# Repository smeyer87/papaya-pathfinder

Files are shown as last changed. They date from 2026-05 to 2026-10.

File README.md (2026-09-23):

# Papaya Pathfinder — Personal Build

<div style="text-align: center;">
  Papaya Pathfinder patch
</div>

This is a personal fork of the open-source [Papaya Pathfinder](https://github.com/tronxi/papaya-pathfinder)
rover project, building the **full-size Pathfinder** with custom electronics
and a from-scratch PCB design. It is not a general-purpose reference for the
upstream project — for that (both rover variants, the Android/desktop
controllers, full parts lists, licensing), see the archived
[upstream README](docs/UPSTREAM_README.md).

This fork intentionally does **not** use `pathfinder-mini`,
`android-controller`, or `desktop-controller` — control is via a standard
R/C transmitter/receiver instead.

## Hardware

- **Controller:** ESP32-S3
- **Radio:** RadioMaster ELRS-RP3-V2 receiver + BETAFPV LiteRadio 2 SE
  transmitter (ELRS V3, 2.4 GHz) — not covered by the upstream project;
  see [`docs/elrs-wiring.md`](docs/elrs-wiring.md)
- **Motor Drivers:** 2× BTS7960/IBT_2
- **Motors:** 6× GA25 DC gear motors (3 per side, ganged — one PWM signal
  per side drives all 3 motors on that side simultaneously)
- **Steering:** 4× Miuzei DS3218 servos (front and rear axles only)
- **Power:** LiPo 3S
- **Voltage Regulation:** UBEC 5V/3A (logic) + UBEC 6V/8A (servos)

Full mechanical parts list and 3D-printable files are unchanged from
upstream — see the [3D-Printed Parts table](docs/UPSTREAM_README.md#3d-printed-parts)
and [`pathfinder/3d-models/`](pathfinder/3d-models/).

## Electronics & PCB design (this fork's main addition)

The stock electronics were originally point-to-point soldered onto a
pre-drilled prototyping board. That's being replaced with a custom PCB,
designed via a YAML-first workflow rather than starting cold in KiCad:

- **[`papaya-wiring-layout.yaml`](papaya-wiring-layout.yaml)** — the single
  source of truth for the *entire* electrical system (battery, fuse,
  switch, terminal blocks, motor drivers, UBECs, ESP32, ELRS receiver,
  motors, servos, and the board's own connectors), not just the board.
  Real wire gauges, real terminal numbering, ground loop verified closed.
- **[`pathfinder/kicad/papaya-pcb/`](pathfinder/kicad/papaya-pcb/)** — the
  KiCad 10 project. The schematic is generated (see below), not hand-drawn;
  the layout, copper pours, routing, and 4 corner mounting holes were then
  done by hand and verified with `kicad-cli` DRC (0 violations) and a full
  net-by-net comparison against the YAML.
- **[`pathfinder/kicad/scripts/generate_schematic.py`](pathfinder/kicad/scripts/generate_schematic.py)** —
  reads the wiring YAML and writes a fully-wired starter schematic (every
  component placed, every net labeled), validated against real KiCad 10 with
  zero ERC errors. Re-run it any time the YAML changes:
  ```
  pip install -r pathfinder/kicad/scripts/requirements.txt
  python pathfinder/kicad/scripts/generate_schematic.py
  ```
- **[`pathfinder/kicad/papaya-pcb/gerbers/`](pathfinder/kicad/papaya-pcb/gerbers/)** —
  fabrication output (Gerbers, Excellon drill file, drill map, job file, and
  a zip of the set) for the board revision ordered from OSH Park.

See **[`docs/development-log.md`](docs/development-log.md)** for the full
write-up of how the wiring model, schematic generator, and PCB layout were
built, and the Phase 1 bring-up narrative (including two real hardware
defects found and fixed — see the ADRs below).

**Status: Phase 1 complete** (2026-09-19) — the rover drives under full
ELRS control. See
[`docs/superpowers/specs/2026-08-16-phase1-current-state.md`](docs/superpowers/specs/2026-08-16-phase1-current-state.md)
for the exit-criteria checklist.

## Documentation

- **[`docs/build-guide.md`](docs/build-guide.md) — start here if you're
  building one of these from scratch**: full parts list through
  fabrication, assembly, firmware flashing, and bring-up testing, written
  to route around every mistake made during this build.
- [`docs/build-notes.md`](docs/build-notes.md) — build journal, gap
  analysis vs. the upstream docs, project goals for this fork
- [`docs/elrs-wiring.md`](docs/elrs-wiring.md) — ELRS receiver wiring,
  binding, and RC channel mapping
- [`docs/servo-zeroing.md`](docs/servo-zeroing.md) — flashing firmware and
  validating steering servo centering
- [`docs/development-log.md`](docs/development-log.md) — wiring model,
  KiCad generator, PCB layout, and Phase 1 bring-up narrative
- [`docs/adr/`](docs/adr/) — architecture decision records for two hardware
  defects found post-fabrication (ESP32 header pin trimming; servo header
  ground isolation) and how they were resolved
- [`docs/phase2/inputs/`](docs/phase2/inputs/) — Phase 2 planning input
  templates (missions, capabilities, sensors/compute, platform,
  assumptions/decisions) feeding the Phase 2 design session
- [`docs/UPSTREAM_README.md`](docs/UPSTREAM_README.md) — archived original
  project README (both rover variants, full parts tables, controllers)

## License

This project is licensed under the **Apache License 2.0** — see
[LICENSE](LICENSE). This fork is derived from
[tronxi/papaya-pathfinder](https://github.com/tronxi/papaya-pathfinder);
see [`docs/UPSTREAM_README.md`](docs/UPSTREAM_README.md) for original
project attribution.

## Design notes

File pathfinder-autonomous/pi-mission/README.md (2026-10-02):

# Papaya Pathfinder — Pi Mission

The MP-1 ("Map/Detect/Explore") mission software: GPS+IMU dead-reckoning
position fusion with a growing error-circle, boustrophedon
coverage-pattern generation, exclusion-zone intrusion checks, obstacle
detection/classification and resume-after-restart reconciliation, and
`MissionRuntime` — the orchestrator that ties all of it into one running
process (startup/resume, the tick loop, command handling, telemetry
cadence, Home-return sync). See
`../../docs/superpowers/specs/2026-09-24-mp1-map-detect-explore-design.md`
for the design this implements, and the "Mission Runtime" section below
for how it actually runs.

`GpsFix`/`ImuReading` are plain data; a sensor-driver layer underneath
`MissionRuntime` produces them from either real or simulated hardware
(see "Sensing backends" below) — this package's own math modules
(`position_fusion.py`, `coverage_pattern.py`, etc.) never touch hardware
directly. Persistence is local-first: `local_store.py`'s SQLite store
holds obstacles/sweep-sessions/telemetry, synced to the backend at a
Home-return checkpoint by `sync_client.py`.

**Time handling:** `position_fusion.py`'s `timestamp` fields are
monotonic seconds (e.g. `time.monotonic()`), used only for computing
elapsed-time deltas -- never wall-clock time. Everything else
(`Obstacle.first_detected_at`, `detected_at`, `now`) is a real UTC
`datetime`.

**Bearing convention:** ultrasonic/camera detections report a bearing
relative to the rover's own heading (0 = straight ahead), not an
absolute compass bearing -- the mast rotates independently of the
chassis. `obstacle_detection.py` combines it with the rover's current
heading before placing the obstacle.

## Run the tests

    python3 -m venv .venv
    source .venv/bin/activate   # Windows: .venv\Scripts\activate
    pip install -r requirements.txt
    pytest -v

## Modules

- `position_fusion.py` — `PositionFusion`: seed with a `GpsFix`, feed
  `ImuReading`s between fixes, read `.current_estimate` for the fused
  position + heading + error-circle radius.
- `coverage_pattern.py` — `generate_coverage_pattern(inclusive, exclusions,
  row_spacing_m)`: ordered lawnmower *legs* — a list of contiguous
  `(lon, lat)` polylines. Each leg is independently drivable; routing
  between legs is the caller's job (an exclusion zone may sit in the gap).
- `exclusion_check.py` — `find_intruded_exclusion(position, exclusions)`:
  which exclusion zone (if any) a position is inside, and how deep.
- `geo_utils.py` — shared degrees/meters helpers (`project_position`,
  `flat_earth_distance_m`) used by every other module.
- `obstacle.py` — `Obstacle`: the detection domain object.
- `classification.py` — `classify_permanence(type, confidence)`: the
  permanent/temporary heuristic, with a low-confidence safety override.
- `obstacle_detection.py` — turns a sensor detection (ultrasonic+camera
  relative-bearing/range, or a bump contact) into an `Obstacle` at an
  absolute position.
- `resume_validation.py` — `reconcile_obstacles(known, fresh, now)`:
  confirms, clears, or flags-as-discrepancy previously known obstacles
  during a resume pass.
- `row_spacing.py` — derives coverage row spacing from sensor detection
  width; validates it against the rover's chosen turn style
  (spin-in-place vs. graceful) and turn diameter.
- `sweep_session.py` — the sweep-session state machine (start/
  interrupt/resume/complete). Build one from a coverage pattern with
  `SweepSession.from_legs(legs, ...)`, which tags each waypoint with its
  `leg_index` so leg boundaries survive; never flatten the legs yourself.
- `exclusion_decision.py` — auto-reverse vs. wait-for-help.
- `gps_loss_decision.py` — continue-on-dead-reckoning vs. stop-and-alert.
- `local_store.py` — SQLite local store for obstacles/sweep-sessions/
  telemetry. Obstacle/session saves commit immediately; telemetry saves
  defer commit to the caller (`commit()`), batched per
  `DEFAULT_TELEMETRY_COMMIT_INTERVAL_S` (currently 60s — change this one
  constant, or pass a different `interval_s` to `should_commit_telemetry`,
  if the SD-card-wear tradeoff ever needs revisiting; see the design
  spec's resolved open items).
- `telemetry_record.py` — `build_telemetry_record()`: the two-tier
  telemetry record's missing-value tagging (present / `"missing"` /
  omitted).
- `sync_client.py` — pushes unsynced local-store records to the
  backend's `/sync/*` endpoints at a Home-return checkpoint. Tests run
  against `httpx.MockTransport`, not a live server -- no MongoDB or
  running backend needed to build or test this module.
- `runtime.py` — `MissionRuntime`: the orchestrator. Owns no business
  logic of its own; ties position fusion, obstacle detection, the
  mission-flow decision modules, telemetry, and sync into one running
  process. Takes a `SensorHub` and an `Esp32Link` as constructor
  arguments (see "Sensing backends" below).
- `runtime_config.py` — named constants and `.env`-loaded settings
  (`TICK_HZ`, poll/sample intervals, GPS-loss thresholds, etc.).
- `esp32_link.py` / `sensor_hub.py` — the `Esp32Link`/`SensorHub`
  Protocols `MissionRuntime` depends on, plus `FakeEsp32Link`/
  `SimulatedSensorHub`, the scripted-per-field test doubles used by most
  of this package's own tests.
- `backend_client.py` — read/poll half of talking to the Backend Core
  API (rover/geofence fetch, command polling); `sync_client.py` is the
  push half.

### Sensing backends

Three things can sit behind the `SensorHub`/`Esp32Link` Protocols,
swapped in via `MissionRuntime`'s constructor without touching
orchestration logic:

- **`sensor_hub.py`'s `SimulatedSensorHub` / `esp32_link.py`'s
  `FakeEsp32Link`** — scripted per-field test doubles. Each test sets
  exactly the value it needs; fields have no relationship to each other.
- **`digital_twin.py`** — one coherent simulated rover world (position,
  heading, speed, a bounded mast sweep, bounded GPS jitter, bump/halt
  detection) that *derives* every sensor reading from shared state, so a
  scenario test can rely on them agreeing with each other the way real
  sensors would.
- **`hardware_esp32_link.py` / `hardware_sensor_hub.py`** — real
  implementations for the breadboard bench rig: NMEA GPS parsing, a
  BNO055-shaped IMU, HC-SR04-style ultrasonic ranging, a thin camera
  pass-through, and the real newline-delimited-JSON Pi↔ESP32 UART
  protocol. Every hardware dependency (a serial-like transport, an I2C
  device, a GPIO pulse timer) is injected via the constructor against a
  `Protocol` defined in the same file, so none of this needs real
  hardware or hardware-specific libraries (`pyserial`, `pigpio`, etc.)
  to unit-test — only to actually run against physical hardware, which
  is bench-time work (constructing the real `serial.Serial`/`pigpio.pi()`
  objects) not yet wired into `__main__.py`.
- **`status_display.py`** — an LCD status display (screen cycling, 2
  soft-key function buttons) reading `MissionRuntime.last_telemetry_
  readings`, the same hardware-driver pattern: logic is fully testable,
  the real PCF8574/1602A write backend is bench-time work.

## Mission Runtime

`python -m papaya_mission` runs the mission loop. Requires `.env` with
`ROVER_ID`, `BACKEND_BASE_URL` (the running Backend Core service), and
`LOCAL_DB_PATH` (SQLite file path — created if absent).

The CLI entrypoint (`__main__.py`) currently wires `SimulatedSensorHub`
and `FakeEsp32Link` — real hardware drivers exist (`hardware_sensor_hub.py`,
`hardware_esp32_link.py`, see "Sensing backends" above) but constructing
the actual hardware objects they're injected with (a real serial port, a
real `pigpio` connection) is bench-time work not yet done, so the CLI
entrypoint hasn't been switched over.

**Note — the swap-in story holds for sensing, not yet for motion.** The
`Esp32Link` contract currently covers bump-safety reporting and
drive-status telemetry only; it has no drive/steering-commanding method
yet, and `MissionRuntime` never issues a movement command anywhere in
`tick()`. Actual navigation (driving toward the next waypoint) is not
yet implemented: this runtime can *detect* waypoint arrival and make
mission-level decisions off it, but it has no way to *cause* that
arrival. The ESP32 firmware plan needs to add both a movement-commanding
method to `Esp32Link` and a navigation step to `tick()` before the rover
can physically move itself.

Per-tick duration is logged; a warning means a tick exceeded its
`TICK_HZ` budget — see the MP-1 Mission Runtime design notes' "Scaling
note" for what that means and what to do about it.

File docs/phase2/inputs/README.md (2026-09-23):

# Phase 2 Planning Inputs

Raw-but-organized planning notes that feed the Phase 2 design session.
These are **inputs**, not a design — nothing here is final until it lands
in a spec under `docs/superpowers/specs/` or an ADR under `docs/adr/`.

Baseline for everything here is the Phase 1 build as documented in
[`../../superpowers/specs/2026-08-16-phase1-current-state.md`](../../superpowers/specs/2026-08-16-phase1-current-state.md)
— don't re-describe Phase 1 hardware in these files, just reference it.

## Files

| # | File | Answers | ID prefix |
|---|---|---|---|
| 0 | [`00-inbox.md`](00-inbox.md) | "I don't know where this goes yet" | — |
| 1 | [`01-missions.md`](01-missions.md) | What should the rover *do*, where, and what's out of scope? | `MP-` |
| 2 | [`02-capabilities.md`](02-capabilities.md) | What logical abilities do those missions require? | `CAP-` |
| 3 | [`03-sensors-compute-electronics.md`](03-sensors-compute-electronics.md) | What sensors, compute, power, and comms hardware supports them? | `SEN-` / `CMP-` / `PWR-` / `COM-` |
| 4 | [`04-physical-platform.md`](04-physical-platform.md) | What mechanical/chassis changes does all of the above need? | `PLT-` |
| 5 | [`05-assumptions-decisions.md`](05-assumptions-decisions.md) | Constraints, assumptions, decisions made, open questions | `CON-` / `A-` / `D-` / `Q-` |

## How to fill these in

- **Don't over-sort.** If a note doesn't obviously belong somewhere, drop
  it in `00-inbox.md`. Each file also has a `Raw notes` section at the
  bottom for anything half-formed.
- **Give items IDs** (`MP-1`, `CAP-4`, …) and reference upstream IDs in a
  `Supports:` line. This is how we keep the files linked without merging
  them. IDs are permanent — if you drop an item, mark it `~~struck~~`
  rather than renumbering.
- **Top-down is ideal, bottom-up is fine.** If a note starts from a
  technology ("I want to try LIDAR"), write it where it belongs and set
  `Supports:` to the mission it enables — or to a learning goal
  (`MP-L1`, etc.) if the real reason is "I want to learn this."
- **Priority** on every mission and capability: `Must` / `Should` /
  `Could`. This is what lets an ambitious list get phased.
- **Uncertainty is valuable.** "Not sure if X or Y" goes straight into
  `05` as an open question (`Q-`) — those become the design session agenda.

## Flow

```
01 Missions ──► 02 Capabilities ──► 03 Sensors/Compute ──► 04 Platform
      │                │                     │                  │
      └────────────────┴──────────┬──────────┴──────────────────┘
                                  ▼
                   05 Constraints / Assumptions /
                      Decisions / Open Questions
```

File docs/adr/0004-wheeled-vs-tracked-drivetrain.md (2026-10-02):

# ADR 0004: Keep wheeled rocker-bogie drivetrain; reject tracked and other alternative architectures

## Status

Accepted — 2026-10-02

## Context

Phase 2 sensor/compute additions are forcing a substantial payload-bay
redesign (`docs/phase2/inputs/04-physical-platform.md` PLT-5), and a
wheel/axle redesign is already underway for two independent reasons: a
recurring printed steering-pivot-pin failure (PLT-7) and a longer
wheelbase needed to match the larger bay (Q-9, 6-vs-8-wheel). With this
much of the drivetrain already open for rework, it's a natural point to
ask whether the overall drivetrain *architecture* — not just the wheel
suspension — is still the right choice, rather than patching the current
approach without reconsidering it.

Four architectures were weighed:

1. **Tracked / caterpillar drivetrain.** Pros: better flotation/traction
   on soft or very uneven ground; steering is typically skid-steer only,
   no steering-knuckle complexity at all. Cons: track tensioners, drive
   sprockets, and track wear/replacement add significant mechanical
   complexity, weight, and cost versus wheels; track maintenance is a
   real recurring burden, not a one-time cost.
2. **Mecanum / omni wheels.** Pros: lateral/strafing movement, tight
   maneuvering in confined spaces. Cons: the small rollers that give
   omni wheels their lateral capability are known to perform poorly
   outdoors on anything but smooth, hard, flat surfaces — grass, dirt,
   and mild unevenness tend to defeat them. Wrong tool for this terrain.
3. **Fully independent coil-over suspension per wheel** (abandon the
   rocker-bogie's passive, geometry-based articulation entirely). Pros:
   simpler single-wheel kinematics; removes the transverse-differential/
   chassis-torsion coupling question entirely (see Q-11 — there'd be
   nothing to couple). Cons: loses the rocker-bogie's ability to span
   step-like obstacles via arm leverage rather than relying purely on
   spring compression; would require re-engineering every wheel mount,
   not just the one joint that's actually failing — discarding the
   "pivot"/"bogey" structural mounts that have never been a problem.
4. **Legged/walking locomotion** (e.g. a Theo Jansen-style linkage).
   Rejected quickly: a large jump in mechanical and control complexity
   with no capability benefit for a mostly-flat terrain profile.

## Decision

**Keep the existing wheeled rocker-bogie drivetrain** (6-wheel today,
likely 8-wheel per Q-9), and retrofit a knuckle-and-shock suspension at
the specific joint that's actually failing (PLT-7) rather than replacing
the drivetrain architecture.

## Rationale

- `A-2` (mild, mostly-flat farm terrain; major hazards geofenced out;
  human-walking-pace operation) doesn't demand tracked-vehicle-grade
  traction or flotation — that capability would solve a problem this
  rover doesn't have.
- The rocker-bogie's structural mounts (the "pivot"/"bogey" parts) have
  never been among the observed failure modes — reusing them, rather
  than replacing the whole architecture, avoids re-solving an
  already-solved problem.
- Tracks, mecanum, and legged locomotion all add substantial cost,
  weight, and complexity with no capability gain for this specific
  mission profile.
- None of the alternatives fix the actual observed failure anyway: the
  printed steering-pivot-pin problem (PLT-7) is a strut/joint design
  issue, not a drivetrain-architecture issue — a tracked vehicle still
  needs a mechanism translating motor rotation into motion and still
  needs shock absorption for ride quality over washboard; changing
  architecture wouldn't make the print-strength problem disappear.

## Consequences

- Keeps the existing motor/servo/driver investment valid and reusable
  (6× GA25 motors, 4× DS3218 servos, 2× BTS7960 drivers) rather than
  stranding it on an architecture change.
- Revisit if `A-2`'s terrain assumption changes — e.g. a future mission
  requires crossing genuinely soft or rough terrain wheels can't handle.
  Considered unlikely given the stated farm-terrain mission profile, but
  not foreclosed.

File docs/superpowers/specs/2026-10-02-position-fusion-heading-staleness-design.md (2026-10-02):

# PositionFusion Heading-Staleness Bug — Design

**Status:** Approved, pending plan
**Related:** `pathfinder-autonomous/pi-mission/papaya_mission/position_fusion.py`, `papaya_mission/runtime.py`

## Problem

`PositionFusion._heading_deg` only updates inside `on_imu_reading()`, which is the method that also does full dead-reckoning (position/velocity/error-radius). `MissionRuntime._read_position` (`runtime.py:315-361`) calls `on_imu_reading` **only** in the `else` branch — when no GPS fix arrived that tick:

```python
if gps_fix is not None:
    self.position_fusion.on_gps_fix(gps_fix)
    self._last_gps_fix_monotonic = now_monotonic
else:
    self.position_fusion.on_imu_reading(imu_reading)
```

On a GPS-healthy rover (the common case — a fix arrives almost every tick), `on_imu_reading` essentially never runs, so `_heading_deg` never advances past whatever it was seeded at. `obstacle_from_ultrasonic_camera_detection` (`obstacle_detection.py`) projects every detection's absolute bearing using `rover_position.heading_deg` — so every logged obstacle gets placed using a stale/zero heading, silently misplacing it, whenever GPS is working normally (i.e. almost always).

A second, related bug compounds this: the very first `PositionFusion` ever constructed, at seed time (`runtime.py:343-345`), also doesn't get a real heading —

```python
self.position_fusion = PositionFusion(seed_fix)
```

— defaults `initial_heading_deg` to `0.0`, even though a real `imu_reading` was already successfully read that same tick (the method returns early with an IMU read failure before reaching this line, so `imu_reading` is guaranteed valid here).

This bug was found during the digital-twin simulator's final review (2026-09-26), logged to memory, explicitly scoped out of that plan as pre-existing and unrelated — never fixed until now.

## `PositionFusion` itself is correct and already tested — the bug is entirely in the caller

`position_fusion.py`'s `on_gps_fix` deliberately never touches heading (position/velocity/error-radius only) — there's an existing, passing test for exactly this: `test_gps_fix_does_not_change_heading` asserts `corrected.heading_deg == 90.0  # unchanged by the GPS fix`. This is correct design: a GPS fix carries no heading information of its own, so `on_gps_fix` has nothing to update heading with. The bug is that nothing else steps in to update heading on a tick where `on_gps_fix` runs instead of `on_imu_reading`.

## Fix

Add a narrow, dedicated method to `PositionFusion` that updates **only** heading — no dt guard, no dead-reckoning math, so it can never be silently skipped the way `on_imu_reading`'s `if dt <= 0: return` guard could skip it:

```python
def on_imu_heading(self, heading_deg: float) -> None:
    self._heading_deg = heading_deg
```

Call it unconditionally, every tick, in `_read_position` — before the `gps_fix is not None` branch, so it runs regardless of which branch follows:

```python
self.position_fusion.on_imu_heading(imu_reading.heading_deg)
if gps_fix is not None:
    self.position_fusion.on_gps_fix(gps_fix)
    self._last_gps_fix_monotonic = now_monotonic
else:
    self.position_fusion.on_imu_reading(imu_reading)
```

In the no-fix branch, `on_imu_reading` will set the same heading value again — harmless redundancy, not worth adding a conditional to avoid, since correctness (heading always reflects the latest real reading) matters more than skipping one redundant assignment.

Also fix the seed-time gap: pass the real heading when constructing the first `PositionFusion`:

```python
self.position_fusion = PositionFusion(seed_fix, initial_heading_deg=imu_reading.heading_deg)
```

## Why not fold heading into `on_gps_fix` instead

Considered and rejected: calling `on_imu_reading` unconditionally every tick (even when a GPS fix also arrives) instead of adding a new method. Rejected because `on_imu_reading`'s `dt <= 0` guard (comparing `ImuReading.timestamp` against `_last_timestamp`) could still silently skip the heading update under certain tick-timing edge cases — real hardware's IMU and GPS readings may come from clocks that aren't perfectly synchronized, so this doesn't fully close the bug, just narrows it. A dedicated, guard-free method closes it completely and leaves the already-tested `on_gps_fix`/`on_imu_reading` dead-reckoning contracts untouched.

## Testing

- `tests/test_position_fusion.py`: a new unit test constructing `PositionFusion`, calling `on_imu_heading(90.0)` directly, and asserting `current_estimate.heading_deg == 90.0` with no position/velocity/error-radius side effects (compare against the state immediately after construction for every other field).
- A new test confirming `on_imu_heading` works independent of `on_gps_fix`/`on_imu_reading` call order — e.g. call `on_gps_fix` first (which doesn't touch heading, per the existing test), then `on_imu_heading`, and confirm heading updates while position stays at the GPS fix's value.
- `tests/test_runtime_tick_sensing.py`: a new integration-style test using the existing `_make_started_runtime`/`SimulatedSensorHub` fixtures — script an `ImuReading` with a non-zero heading alongside a GPS fix that arrives every tick (the common, previously-broken case), tick `MissionRuntime`, and assert `runtime.position_fusion.current_estimate.heading_deg` reflects the scripted IMU heading, not `0.0` or the seed value. This is the actual regression guard for the bug as experienced in production.
- A new test for the seed-time fix: assert that `position_fusion.current_estimate.heading_deg` on the very first tick (where `PositionFusion` is constructed) already reflects the scripted IMU heading, not the `0.0` default.

## Out of scope

- No change to `obstacle_detection.py` — it already correctly consumes `rover_position.heading_deg`; the bug was entirely in that value being stale, not in how it's used.
- No change to `on_gps_fix`'s or `on_imu_reading`'s existing dead-reckoning behavior.

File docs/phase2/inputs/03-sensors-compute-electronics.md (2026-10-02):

# 03 — Sensors, Compute & Electronics

Hardware needed to deliver the capabilities in
[`02-capabilities.md`](02-capabilities.md). Specific part names are
welcome here, including "candidates I'm considering" — note links,
prices, and why.

Phase 1 electronics baseline: see
[`../../superpowers/specs/2026-08-16-phase1-current-state.md`](../../superpowers/specs/2026-08-16-phase1-current-state.md)
and [`../../../pathfinder/BOM.md`](../../../pathfinder/BOM.md).

## Sensors

<!-- Copy per sensor. -->

### SEN-1: Ultrasonic

- **Supports:** CAP-9, MP-1
- **Candidates:** HC-SR04-class trigger/echo module — starting point is
  the unit already bundled on the 4Tronix M.A.R.S. Rover mast (alongside
  its Pi AI Camera mount), since that mast is also a PLT-2 reuse
  candidate. Any HC-SR04-class module reaches ~3-4m reliably on
  reasonably-sized, perpendicular targets — soft/angled/small targets
  reduce effective range, a physics limit of the technology, not a
  specific part's shortcoming. I2C ToF modules (VL53L0X/L1X-class) were
  considered and rejected for this role: shorter max range (~2-4m) and
  known to struggle outdoors in direct sunlight (ambient IR swamps the
  sensor) — a real problem for a farm rover, not just a range tradeoff.
- **Interface/owner (see D-6):** Pi-managed via GPIO trigger/echo
  (`pigpio`'s DMA-based edge timing keeps microsecond accuracy despite
  Linux scheduling jitter — a well-trodden HC-SR04+Pi combo). Chosen
  over ESP32-managed specifically to avoid inventing a new
  ultrasonic-over-UART message on the Pi↔ESP32 link, and to keep all
  ranging sensors (camera + ultrasonic) consistently Pi-side.
- **Mounting needs:** Assumes a rotating mast (PLT-2); provides bearing
  and range.
- **Notes:** Considered an obvious "yes" — low power, low capability,
  easy to integrate for basic bearing-and-range sensing.
- **Vertical beam cone — plan to test empirically (2026-09-30):** an
  HC-SR04-class sensor's vertical beam is narrow (~15° effective), and
  whether it covers payload-bay height (vs. only ground-level
  obstacles) depends on mount height and distance, neither fixed yet.
  Rather than calculate this from a datasheet, once the breadboard's
  ultrasonic is wired up: move a target vertically at a few distances
  and record where detection drops out. Feeds directly into SEN-4's
  payload-bay-corner bump-sensor question — if the cone already covers
  that height, a bump sensor there is redundant; if not, it's the gap
  that sensor needs to close.

### SEN-2: LiDAR

- **Supports:** CAP-3, CAP-9
- **Candidates:** Not yet specified.
- **Mounting needs:** Mast-mounted, TBD.
- **Notes:** Higher power draw than ultrasonic. Primary value seen in
  the mapping mission (MP-1). Open question on whether it's useful at a
  reduced scan frequency for general (non-mapping) use to limit power
  draw (see Q-2 in
  [`05-assumptions-decisions.md`](05-assumptions-decisions.md)).

### SEN-3: AI Camera (Raspberry Pi AI Camera)

- **Supports:** CAP-8, MP-2, MP-4
- **Candidates:** Raspberry Pi AI Camera — edge object classification.
  **Confirmed (D-6, 2026-09-30):** v1 unit already owned; a v2 may also
  be on hand, unverified. A Pi HD Camera (non-AI) is also available as a
  fallback/secondary. Connects via the Pi's CSI port.
- **Mounting needs:** TBD — co-mounted with SEN-1 on the 4Tronix mast is
  the starting candidate.
- **Notes:** High priority — some form of camera is required in all
  scenarios. The Pi AI Camera's edge-classification capability was the
  key factor pulling the platform toward the hybrid controller design
  (see D-6 in 05).

### SEN-4: Touch / Bump Sensors

- **Supports:** CAP-9
- **Candidates:** Not yet specified — a minimal set at the rover
  corners. **Breadboard bench rig (2026-09-30):** 2 switches (left/right)
  for this first pass — see `docs/wiring/breadboard-wiring-layout.yaml`.
- **Production count/placement (2026-09-30):** leaning toward all 4
  axle corners, possibly *also* the payload bay's corners if it ends up
  tall enough — not just ground-level. Open question: whether the
  payload-bay height falls inside or outside SEN-1's ultrasonic vertical
  beam cone. If it's inside the cone, the ultrasonic may already catch
  mid-height obstacles the camera/ultrasonic combo would otherwise miss
  (a signpost, a branch at hip height); if it's outside, that's exactly
  the gap a payload-bay-corner bump sensor would need to cover. See
  SEN-1's note on empirically testing the real cone once the breadboard
  sensor is wired up, rather than guessing from a datasheet.
- **Mounting needs:** Corner-mounted, low to the ground (to catch
  obstacles below the height of ultrasonic/LiDAR/camera sensing) — and
  possibly also at payload-bay-corner height, pending the vertical-cone
  question above.
- **Notes:** Should give immediate stop-forward-motion feedback; ideally
  integrates with CAP-9 to interrupt the current path and back away/
  reroute around the detected object. Motivation (2026-09-30, from real
  test runs): small ground obstacles — a fallen branch, a rut, tall
  grass/plants — likely won't register via camera or ultrasonic at all,
  but still impair wheel operation; see the training-mode inbox note for
  the related idea of capturing recovery maneuvers for these cases.

### SEN-5: IMU (Inertial Measurement Unit)

- **Supports:** CAP-9, CAP-3
- **Interface class settled:** I2C (4-wire, shares a bus trivially with
  other I2C devices — near-zero pinout risk). 9-DOF with a magnetometer
  (not a bare 6-DOF accel/gyro-only part like the MPU-6050), since
  `papaya_mission.position_fusion.ImuReading.heading_deg` is a compass
  heading, which a 6-DOF part can't directly provide.
- **Purchased for bench evaluation, both NRND (2026-09-30):** Adafruit
  BNO055 (onboard sensor fusion — fastest path to a working
  `heading_deg`) and SparkFun ICM-20948 board. Both fine for breadboard
  eval, but **not for the permanent PCB** — BNO055 is NRND, and the
  ICM-20948 faces an imminent Last-Time-Delivery (~2026-10-30) because
  AKM is discontinuing the AK09916C magnetometer it depends on. TDK's
  own suggested replacement path: ICM-42688-P/42670-P (6-axis only) plus
  a separate current magnetometer — the QMC5883L already bundled on the
  spare MicroAir GPS board (see SEN-6) could plausibly fill that role
  later without a new purchase. Process lesson from this purchase:
  verify NRND/EOL status before buying a specific SKU, not just
  confirming the interface class.
- **Breadboard wiring (2026-09-30):** wired one at a time, not
  simultaneously — BNO055 active, ICM-20948 as a direct swap-in using
  the same 4 points (SDA/SCL/VCC/GND). See
  `docs/wiring/breadboard-wiring-layout.yaml`.
- **Interface/owner (see D-6):** Pi-managed, I2C.
- **Mounting needs:** TBD.
- **Still open for the permanent PCB:** exact SKU, given both on-hand
  parts are NRND. Revisit before the real board respin — TDK's
  suggested path above is the current leaning, not yet decided.

### SEN-6: GPS

- **Supports:** CAP-2, CAP-3, CAP-11, CAP-4
- **Interface class settled:** UART/NMEA-0183 (4-wire — near-zero
  pinout risk). u-blox NEO-family (NEO-6M/7M/8M/M9N/M10) is the de facto
  hobby/prosumer standard, consistent pinout across the family, heavily
  documented.
- **Confirmed long-term pick (2026-09-30): SparkFun NEO-M9N (SMA
  variant).** Verified active/production, u-blox's own recommended
  migration target away from the NRND NEO-M8N, open schematics, panel-
  mount SMA for a separately-mounted antenna. Chosen on the merits for
  long-term use, not optimized for breadboard (Qwiic) convenience. Also
  on hand for bench eval: MicroAir M10G (has an embedded 18×18×4mm patch
  antenna, no external antenna needed — a useful spare/fallback, bundled
  QMC5883L magnetometer noted under SEN-5 as a possible future IMU
  component).
- **Gap: GPS-specific antenna not yet sourced.** The NEO-M9N SMA board
  expects an external antenna (no onboard patch) — needs sourcing before
  the breadboard can get a real fix, independent of the Q-6 antenna-mast
  question (GPS/LoRa/ELRS each need their own distinct, correctly-tuned
  antenna; they cannot share one — see Q-6 in 05).
- **Interface/owner (see D-6):** Pi-managed, UART.
- **Decimeter-accuracy target may be stricter than actually needed** —
  worth checking against `position_fusion.py`'s existing dead-reckoning
  error budget (`GPS_LOSS_MAX_ERROR_RADIUS_M = 5.0` in the Mission
  Runtime code already tolerates several meters of drift between fixes)
  before shopping for RTK-class hardware to hit decimeter accuracy.
- **Mounting needs:** Antenna integration TBD (see Q-6 in 05).
- **Notes:** Almost certainly mandatory. Update frequency can be
  moderate — rover is low-speed, so a few fixes per minute is likely
  sufficient. HDOP-based accuracy heuristic (`accuracy_m = hdop * 5.0`)
  is implemented in `hardware_sensor_hub.py`, documented there as an
  approximation to refine once real bench fix data exists.

## Compute

Where does the thinking happen? The ESP32-S3 alone, the ESP32 plus a
companion computer (Raspberry Pi, Jetson, etc.), or offboard (laptop over
WiFi)? Capture leanings and reasons, even if undecided.

### CMP-1: Core platform architecture

- **Supports:** CAP-8, CAP-9, CAP-3, all missions
- **Decided (D-6):** Hybrid — Pi runs mission logic and owns all
  sensing (GPS/IMU/ultrasonic/camera); ESP32 stays scoped to drive-train
  actuation, bump-safety interrupt, drive-status, geofence push (purpose
  TBD — not yet called by `MissionRuntime`), and OTA (Pi downloads over
  WiFi, flashes the ESP32 locally over the serial link — no independent
  ESP32 networking either way). **Pi model: Raspberry Pi 5** (4GB or
  8GB, both on hand; NVMe HAT available to avoid SD-card wear) — see
  D-6 in [`05-assumptions-decisions.md`](05-assumptions-decisions.md).

## Power

New loads, runtime targets, battery changes, extra regulator rails.

### PWR-1: Cell-level LiPo monitoring

- **Notes:** Currently uses a separate manual balance-lead dongle to
  read cell voltages. Want to build a connector that captures per-cell
  voltage through this connection and feeds it into telemetry (CAP-4),
  enabling low-voltage alarms that protect the battery.

### PWR-2: Additional power measurement points

- **Notes:** Open question on which additional points are worth
  instrumenting for voltage/current — e.g. per-motor/per-servo, per-
  sensor, per-rail (see Q-5 in 05). Sampling should be configurable:
  full detail at startup as a validation check, then reduced-frequency
  sampling in normal operation to limit telemetry volume, with
  mission-driven toggles for detail level and sample rate. If a
  multi-battery configuration is adopted, power management must cover
  all sources.

### PWR-3: Charging & solar assist

- **Parts on hand (2026-09-30):** several small lightweight 7.2V/200mA
  solar panels, earmarked for logic/electronics only, not motors/servos
  — matches the "sustain control electronics/radios, not drive" lean
  below. Not a critical decision yet.
- **Main battery:** 5000mAh 3S LiPo, already in use and reported to do
  well at the rover's low-speed Phase 1 operation (see CON-B5 for the
  existing UBEC/power-rail baseline).
- **Notes:** Onboard solar considered "nice to have" — likely
  insufficient for motors/servos but might sustain control electronics/
  radios at a lower bulk/weight cost (see Q-7 in 05). Independent of
  solar, want easily accessible charging points, ideally without
  removing batteries; any external power connection needs a cover to
  avoid short-circuit risk from weather.

## Communications & telemetry

Video, telemetry back to the operator, WiFi/ELRS telemetry, data logging,
remote kill switch.

### COM-1: WiFi

- **Confirmed (D-6):** Pi 5 has onboard WiFi — this is the rover's
  comms path (backend sync, OTA firmware download, Management UI). Not
  the ESP32's job; see D-6.
- **Notes:** High bandwidth, limited range; suitable for local/on-
  premise hosting.

### COM-2: LoRa / LoRaWAN

- **Parts on hand (2026-09-30):** LoRa hardware available, not yet
  used. Would need a matching receiver device at the garage base
  station — inherent to point-to-point LoRa, not an added complication
  — likely a small Pi Pico- or ESP-class board, a separate build from
  the rover itself. Deferred; not a breadboard concern.
- **Confirmed low-risk to defer (2026-09-30):** no pin/bus conflict
  with anything decided so far — common LoRa modules are SPI (unclaimed
  by GPS/IMU/ultrasonic/camera) or a self-contained UART module, and Pi
  5's RP1 makes a second UART easy if needed. Software-wise it's
  additive — a new module parallel to `backend_client.py` carrying a
  small command/telemetry message set, not a retrofit of sensing or the
  existing HTTP sync path (which can't carry LoRa's bandwidth anyway).
  Note `local_store`'s store-and-forward design already tolerates WiFi
  gaps today (buffers and catches up the backend later) — LoRa's real
  marginal value is *real-time* command/telemetry while actually out of
  WiFi range (e.g. a remote stop), a genuinely new capability worth
  having for a true field build, not a fix for something broken.
- **Notes:** Long-range, low-power; for basic telemetry and low-
  bandwidth commands; not suitable for large data transfers (e.g.
  images/maps).

### COM-5: Local status LCD

- **Supports:** CAP-4 (telemetry), general bench/field validation.
- **Confirmed (2026-09-30): 1602A 16×2 character LCD with a PCF8574 I2C
  backpack, address `0x27`** — matches `github.com/UCTRONICS/KB0005`'s
  reference driver exactly. Two backpack-equipped units on hand (one
  active, one spare), plus a third bare 1602A (no backpack) as spare.
  Powered from the Pi's 5V pin. An "Inland 3.5 inch TFT Touch Screen
  Monitor" and standard 7" Pi displays are also on hand as alternates,
  not used for this role.
- **Interface/owner (see D-6):** Pi-managed, I2C. No address conflict
  with anything decided so far (IMU 0x28/0x68-class, GPS I2C mode 0x42,
  QMC5883L 0x0D).
- **Subscreen content and navigation, built (2026-10-01):** implemented
  in `papaya_mission/status_display.py` — 4 screens (position/heading,
  mission mode+alert, obstacle count+last type, drive throttle+halted
  status), cycled via up/down buttons, with 2 soft-key function buttons
  whose meaning depends on the current screen. Reads
  `MissionRuntime.last_telemetry_readings`, the same state the
  telemetry pipeline samples — a live cross-check on what the same
  tick's record reports, as originally proposed. Real hardware write
  backend (the actual PCF8574 byte-banged protocol) is bench-time work,
  not yet built.

### COM-3: Cellular

- **Notes:** Out of scope for Version 2 (see D-1 in 05) — cost and SIM/
  plan overhead not justified. A far-future self-hosted legacy 1G/2G
  private network was floated but is explicitly not a Version 2
  concern.

### COM-4: Zigbee mesh (rover-to-rover relay)

- **Notes:** "Nice to have" multimode capability — would let rovers
  relay messages to each other to extend effective range.

## PCB / wiring impact

Anything you already know about new connectors, a board respin, and so
on. (See constraints in `05` for current pin availability.)

- Any new sensor connectors (cell-tap for PWR-1, bump sensors, IMU,
  LiDAR, AI camera, GPS) mean hand-wiring or a board respin against the
  current 2-layer PCB (CON-B4).
- Antenna consolidation (single mast-integrated antenna structure vs. a
  "nest" of separate antennas for ELRS/LoRa/WiFi/GPS) affects both
  feed-line routing and mast design — open question, see Q-6 in 05 and
  PLT-2 in [`04-physical-platform.md`](04-physical-platform.md).

## Raw notes

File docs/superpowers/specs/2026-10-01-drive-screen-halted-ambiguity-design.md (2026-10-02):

# Drive-Screen Halted/Running Ambiguity — Design

**Status:** Approved, pending plan
**Related:** `docs/phase2/inputs/00-inbox.md` (follow-up logged 2026-10-01), `pathfinder-autonomous/pi-mission/papaya_mission/status_display.py`

## Problem

`_render_drive`'s current implementation:

```python
def _render_drive(state: dict[str, Any]) -> tuple[str, str]:
    throttle = state.get("throttle_position", 0.0)
    halted = state.get("halted_on_contact", False)
    return (f"Throttle: {throttle:.2f}", "HALTED" if halted else "running")
```

`state.get("halted_on_contact", False)` cannot distinguish "confirmed not halted" from "the key is absent." The key is genuinely absent in two real situations:

- `MissionRuntime._sample_telemetry_if_due` omits `halted_on_contact` from `last_telemetry_readings` whenever `esp32_link.status()` raises — a deliberate choice (don't assert a not-halted state that wasn't actually confirmed), added in the runtime-state-gap plan.
- Before the very first telemetry sample ever completes, `last_telemetry_readings == {}`.

In both cases, the LCD currently shows "running" — exactly the moment a bench operator would be looking at the screen to find out whether the rover is actually stuck.

## Fix

Check key presence instead of relying on a default value, and give the "we don't know" case its own distinct label:

```python
def _render_drive(state: dict[str, Any]) -> tuple[str, str]:
    throttle = state.get("throttle_position", 0.0)
    if "halted_on_contact" not in state:
        status_text = "LINK?"
    else:
        status_text = "HALTED" if state["halted_on_contact"] else "running"
    return (f"Throttle: {throttle:.2f}", status_text)
```

`"LINK?"` fits well within the 16-character line width alongside `"Throttle: X.XX"` (15 chars). Localized to `_render_drive` only — no other screen has this ambiguity: `obstacle_count`/`last_obstacle_type`/`nav_mode`/`mission_alert` are all either always present once any sample has run, or have a default that's correct even pre-sample.

## Testing

- `pathfinder-autonomous/pi-mission/tests/test_status_display.py`: the existing `test_default_screens_render_without_raising_on_an_empty_state` only asserts `isinstance(line1, str)`/`isinstance(line2, str)` — it does not assert specific content, so it needs no change and will continue to pass (now rendering `"LINK?"` instead of `"running"` for the drive screen on an empty state, which is more correct, not a regression). Add one new, more targeted unit test asserting the unknown-state path explicitly: `_render_drive({})` (or any dict missing `"halted_on_contact"`) returns `"LINK?"` as its second line, and `_render_drive({"halted_on_contact": False})` still returns `"running"` (confirms the fix didn't flip the meaning of an explicit `False`).
- `pathfinder-autonomous/pi-mission/tests/test_status_display_integration.py`: add one new integration test alongside the existing `test_status_display_renders_real_runtime_state_without_raising`, following its exact fixture pattern (real `MissionRuntime`, real `StatusDisplay`, `_FakeLcdWriter`). Monkeypatch `runtime.esp32_link.status` to raise (matching the pattern already used in `test_runtime_tick_sensing.py`'s `_boom` helper), force a telemetry sample, tick, then assert the drive screen's rendered second line is `"LINK?"` — proving the fix holds end-to-end through a real runtime tick, not just at the renderer-function level.

## Out of scope

- No changes to `runtime.py` — `last_telemetry_readings` already omits the key correctly on a failed read; this fix is entirely on the consuming side.
- No changes to any other screen's renderer.

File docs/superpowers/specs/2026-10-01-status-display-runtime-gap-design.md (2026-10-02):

# StatusDisplay / Runtime State Gap — Design

**Status:** Approved, pending plan
**Related:** `docs/superpowers/plans/2026-09-30-breadboard-hardware-drivers.md` (where the gap was found), `pathfinder-autonomous/pi-mission/papaya_mission/status_display.py`, `pathfinder-autonomous/pi-mission/papaya_mission/runtime.py`

## Problem

`status_display.py`'s four default screens (`_render_position`, `_render_mission`, `_render_obstacles`, `_render_drive`) read a `dict[str, Any]` state snapshot that `MissionRuntime` does not currently produce anywhere:

- The closest candidate, `readings`, is a local variable built fresh inside `_sample_telemetry_if_due` every `TELEMETRY_SAMPLE_INTERVAL_S` and handed straight to `build_telemetry_record` — never stored on `self`, so nothing outside that one method can read it.
- `build_telemetry_record`'s output isn't a substitute either: it replaces every key outside the caller's `expected_metrics` with the string `"missing"` (`telemetry_record.py:28`). `_render_position`'s `position is None` guard doesn't catch that sentinel, so unpacking `lon, lat = "missing"` raises.
- `obstacle_count`, `last_obstacle_type`, and `halted_on_contact` are not tracked as runtime state at all today. Obstacles are persisted to `local_store` one row at a time with no running count kept; `halted_on_contact` is read from `self.esp32_link.status()` only inside `_handle_resume_sweep`, a command handler that isn't called every tick.

Net effect: there is currently no way to wire a live `StatusDisplay` to a real `MissionRuntime` without it crashing or showing permanently-empty obstacle/drive screens.

## Decisions made during brainstorming

- **Scope: local/live only, not synced.** The three new fields get added to a live snapshot the LCD reads, but are deliberately kept out of `MP1_EXPECTED_METRICS` (`runtime_config.py`) and the backend sync path. Adding them to the ground-control telemetry package is a good long-term idea but a separate, bigger-picture change — logged as a follow-up, not built here.
- **Obstacle counter scope: count all detections.** `_save_obstacle()` currently returns early (without persisting) when no sweep session is active. The new counter increments regardless — it answers "what has the rover reacted to," not "what got a durable row."
- **Obstacle counter lifetime: resets per sweep session.** Zeroed in `handle_start_sweep()`, so the LCD shows "this mission," not a lifetime total that keeps climbing across a bench day of many short test sweeps.

## Architecture

All changes are additive to `runtime.py` (and its tests). **`status_display.py` itself needs no changes** — its renderers were already written against exactly this state shape; the gap was entirely on the producing side.

### New `MissionRuntime` state

```python
self.last_telemetry_readings: dict[str, Any] = {}
self._obstacle_count: int = 0
self._last_obstacle_type: str = "-"
```

Declared in `__init__` alongside the other per-task state fields, consistent with the file's existing "declared here so every task's tests can construct one consistent `__init__`" convention.

### `_sample_telemetry_if_due`: expose the pre-sentinel snapshot, add the missing fields

After `readings` is fully built (same point where it's currently handed to `build_telemetry_record`), add the three new keys and store the snapshot:

```python
readings["obstacle_count"] = self._obstacle_count
readings["last_obstacle_type"] = self._last_obstacle_type

try:
    halted_on_contact = self.esp32_link.status().halted_on_contact
except Exception:
    logger.warning("ESP32 status read failed -- leaving halted_on_contact out of this sample", exc_info=True)
    halted_on_contact = None
if halted_on_contact is not None:
    readings["halted_on_contact"] = halted_on_contact

self.last_telemetry_readings = readings
```

This mirrors the existing `read_drive_status()` try/except immediately above it (same file, same method) — a transient ESP32-link failure degrades this one field for this one sample rather than raising. `last_telemetry_readings` is assigned the *same* `readings` dict that (minus these three keys, since they're not in `expected_metrics`) goes on to `build_telemetry_record` — one dict, two uses, no duplication.

### `_save_obstacle`: count every detection

```python
def _save_obstacle(self, obstacle, *, obstacle_id: str | None = None) -> None:
    self._obstacle_count += 1
    self._last_obstacle_type = obstacle.type
    if self.sweep_session is None:
        return
    ...  # unchanged
```

Placed before the existing early-return so it fires whether or not the obstacle gets persisted, per the "count all detections" decision.

### `handle_start_sweep`: reset the counter

```python
def handle_start_sweep(self, payload: dict[str, Any]) -> None:
    self._obstacle_count = 0
    self._last_obstacle_type = "-"
    ...  # existing body
```

`"-"` matches `_render_obstacles`'s own existing default (`state.get("last_obstacle_type", "-")`), so a fresh session and a session with no obstacles yet render identically.

## Testing

- **Unit tests in `test_runtime_*`** (extending whichever existing test module already covers `_sample_telemetry_if_due`/`_save_obstacle`/`handle_start_sweep`):
  - `last_telemetry_readings` is populated after a tick and contains `obstacle_count`, `last_obstacle_type`, and (when the fake `Esp32Link` reports a status) `halted_on_contact`.
  - `_obstacle_count` increments on a bump contact with no active sweep session (count-all-detections behavior), and the obstacle is *not* persisted to `local_store` in that case (existing behavior, now explicitly asserted alongside the count).
  - `_obstacle_count`/`_last_obstacle_type` reset to `0`/`"-"` when `handle_start_sweep` starts a new session, even if a prior session left them non-zero.
  - A failing `esp32_link.status()` degrades only `halted_on_contact` for that sample (the rest of `readings` is unaffected), matching the existing `read_drive_status` failure-handling test's shape.
- **New integration test**: construct a real `MissionRuntime`, drive it through `startup()` → `handle_start_sweep()` → a few `tick()` calls with a fake sensor hub that reports a bump/obstacle, then construct a real `StatusDisplay` and call `.refresh(runtime.last_telemetry_readings)` for each of the four `DEFAULT_SCREENS`, asserting each renders without raising and that the obstacle/drive screens show the expected non-default values (not just "doesn't crash" — the earlier integration test from the hardware-drivers plan proved connectivity without ever exercising `status_display.py`; this one specifically closes that gap).

## Out of scope / follow-ups

- Adding `obstacle_count`/`last_obstacle_type`/`halted_on_contact` to `MP1_EXPECTED_METRICS` and the backend sync path — deferred per the user's explicit call to keep this bench-focused for now.
- Any change to `status_display.py` itself — not needed; the gap was entirely in what `runtime.py` exposed.
- Real hardware wiring (`StatusDisplay` + a real LCD backend) — already covered by the breadboard hardware-drivers plan's bench-time scope, unaffected by this change.

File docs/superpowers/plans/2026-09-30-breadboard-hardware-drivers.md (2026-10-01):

# Breadboard Hardware Drivers Implementation Plan

> **For agentic workers:** REQUIRED SUB-SKILL: Use superpowers:subagent-driven-development (recommended) or superpowers:executing-plans to implement this plan task-by-task. Steps use checkbox (`- [ ]`) syntax for tracking.

**Goal:** Build real, Protocol-conforming `SensorHub`/`Esp32Link` driver implementations (`hardware_sensor_hub.py`, `hardware_esp32_link.py`) and the LCD status display (`status_display.py`) for the breadboard bench rig, so the existing, already-tested `MissionRuntime` can run against real hardware the same way it already runs against `SimulatedSensorHub`/the digital twin.

**Architecture:** Every hardware-touching object (a serial port, an I2C device, a GPIO pulse timer, an LCD's byte-banged write sequence, a camera classifier, an `esptool` invocation) is injected into these classes via the constructor, typed against a small `Protocol` defined locally in the same file — never imported as a concrete hardware library. That keeps 100% of the logic in this plan (message framing, state caching, NMEA parsing, screen content, button dispatch) fully unit-testable with in-memory fakes, with zero dependency on real hardware or hardware-specific Python packages (`pyserial`, `pigpio`, `adafruit-blinka`, `picamera2`) being installed or importable in this environment.

**Tech Stack:** Python 3.12, pytest — no new dependencies. Reuses the existing `GpsFix`/`ImuReading` (`position_fusion.py`), `ObstacleDetection` (`sensor_hub.py`), `BumpEvent`/`DriveStatus`/`Esp32Status` (`esp32_link.py`) types unchanged.

## Global Constraints

- Additive only: `sensor_hub.py`, `esp32_link.py`, and `runtime.py` are untouched. This plan adds three new files and their tests.
- **No hardware-specific imports anywhere in these files.** `pigpio`, `pyserial` (`serial`), `adafruit-blinka`/`adafruit-circuitpython-bno055`, and `picamera2` must never appear as top-level (or any) imports in `hardware_sensor_hub.py`, `hardware_esp32_link.py`, or `status_display.py`. Every hardware dependency is received via constructor injection, typed against a `Protocol` defined in the same file. `pathfinder-autonomous/pi-mission/requirements.txt` is **not** modified by this plan.
- **Constructing real hardware objects is out of scope for this plan** — a real `serial.Serial`, a real `pigpio.pi()` connection, a real Adafruit BNO055 device, a real picamera2/IMX500 classifier, and a real `esptool.py` invocation are all bench-time work, done once at the workbench with real hardware and current library docs in hand — consistent with the same decision already made for the ESP32 firmware itself.
- The bench rig has no mast-rotation servo wired (not part of `docs/wiring/breadboard-wiring-layout.yaml`) — the ultrasonic sensor is simply forward-facing. `ObstacleDetection.relative_bearing_deg` is always `0.0` in this plan's ultrasonic driver.
- GPS accuracy is derived from the GGA sentence's HDOP field via a documented heuristic (`accuracy_m = hdop * 5.0`, a typical SBAS-corrected user-equivalent-range-error estimate) — an approximation to refine once real bench fix data exists, not a precise spec.
- IMU forward-acceleration axis choice (which of the BNO055's three linear-acceleration axes is "forward") assumes a specific physical mounting orientation and is flagged in code for confirmation once physically mounted.
- The camera driver is a thin Protocol-conformance wrapper only — the real Pi AI Camera / picamera2 / IMX500 classification backend is explicitly deferred to bench time (its API is fast-moving and best confirmed against the actual camera and current docs, not guessed at here).
- Design spec: `docs/superpowers/specs/2026-09-30-breadboard-bench-rig-design.md`.

---

## File Structure

```
pathfinder-autonomous/pi-mission/
  papaya_mission/
    hardware_esp32_link.py   # NEW -- HardwareEsp32Link: real Esp32Link over
                              #        an injected transport (serial-like)
    hardware_sensor_hub.py   # NEW -- HardwareGpsSource, HardwareImuSource,
                              #        HardwareUltrasonicSource,
                              #        HardwareCameraSource, HardwareSensorHub
    status_display.py        # NEW -- StatusDisplay, Screen, DEFAULT_SCREENS
  tests/
    test_hardware_esp32_link.py        # NEW
    test_hardware_sensor_hub.py        # NEW
    test_status_display.py             # NEW
    test_hardware_drivers_integration.py  # NEW -- end-to-end against MissionRuntime
```

---

### Task 1: Hardware Esp32Link driver

**Files:**
- Create: `pathfinder-autonomous/pi-mission/papaya_mission/hardware_esp32_link.py`
- Test: `pathfinder-autonomous/pi-mission/tests/test_hardware_esp32_link.py`

**Interfaces:**
- Consumes: `papaya_mission.esp32_link.{BumpEvent, DriveStatus, Esp32Status}` (unchanged).
- Produces: `HardwareTransport` (`Protocol`: `readline() -> bytes`, `write(data: bytes) -> None`), `FlashRunner` (`Protocol`: `__call__(port: str, firmware_path: str) -> bool`), `HardwareEsp32Link(transport: HardwareTransport, port: str, flash_runner: FlashRunner = ...)` implementing `poll_bump_events`, `status`, `read_drive_status`, `send_geofence_update`, `trigger_ota` per the existing `Esp32Link` Protocol. Task 5 passes an instance of this straight to `MissionRuntime(esp32_link=...)`.

- [ ] **Step 1: Write the failing tests**

```python
# pathfinder-autonomous/pi-mission/tests/test_hardware_esp32_link.py
import json

from papaya_mission.hardware_esp32_link import HardwareEsp32Link

class _FakeTransport:
    def __init__(self, lines: list[bytes] | None = None):
        self._lines = list(lines or [])
        self.written: list[bytes] = []

    def readline(self) -> bytes:
        if self._lines:
            return self._lines.pop(0)
        return b""

    def write(self, data: bytes) -> None:
        self.written.append(data)

def _line(message: dict) -> bytes:
    return (json.dumps(message) + "\n").encode("utf-8")

def test_poll_bump_events_returns_empty_when_nothing_arrived():
    link = HardwareEsp32Link(transport=_FakeTransport(), port="/dev/fake")

    assert link.poll_bump_events() == []

def test_poll_bump_events_drains_bump_lines_and_consumes_once():
    transport = _FakeTransport([_line({"type": "bump"}), _line({"type": "bump"})])
    link = HardwareEsp32Link(transport=transport, port="/dev/fake")

    events = link.poll_bump_events()
    assert len(events) == 2
    assert link.poll_bump_events() == []

def test_status_reflects_latest_heartbeat_halted_flag():
    transport = _FakeTransport([
        _line({"type": "status", "halted": False, "throttle": 0.0}),
        _line({"type": "status", "halted": True, "throttle": 0.3}),
    ])
    link = HardwareEsp32Link(transport=transport, port="/dev/fake")

    assert link.status().halted_on_contact is True

def test_read_drive_status_reflects_latest_heartbeat_throttle():
    transport = _FakeTransport([_line({"type": "status", "halted": False, "throttle": 0.42})])
    link = HardwareEsp32Link(transport=transport, port="/dev/fake")

    status = link.read_drive_status()
    assert status.servo_positions_deg == {}
    assert status.throttle_position == 0.42

def test_malformed_line_is_skipped_without_raising():
    transport = _FakeTransport([b"not json at all\n", _line({"type": "bump"})])
    link = HardwareEsp32Link(transport=transport, port="/dev/fake")

    events = link.poll_bump_events()
    assert len(events) == 1

def test_unknown_message_type_is_ignored():
    transport = _FakeTransport([_line({"type": "something_unexpected"})])
    link = HardwareEsp32Link(transport=transport, port="/dev/fake")

    assert link.status().halted_on_contact is False
    assert link.poll_bump_events() == []

def test_send_geofence_update_writes_json_line_and_records_call():
    transport = _FakeTransport()
    link = HardwareEsp32Link(transport=transport, port="/dev/fake")

    link.send_geofence_update(["zone-1", "zone-2"])

    assert link.geofence_updates_sent == [["zone-1", "zone-2"]]
    written = json.loads(transport.written[0].decode("utf-8").strip())
    assert written == {"type": "geofence_update", "zone_ids": ["zone-1", "zone-2"]}

def test_trigger_ota_invokes_flash_runner_with_port_and_path_and_records_call():
    calls = []

    def fake_flash_runner(port: str, firmware_path: str) -> bool:
        calls.append((port, firmware_path))
        return True

    link = HardwareEsp32Link(transport=_FakeTransport(), port="/dev/fake", flash_runner=fake_flash_runner)

    link.trigger_ota("/firmware/v2.bin")

    assert link.ota_triggers == ["/firmware/v2.bin"]
    assert calls == [("/dev/fake", "/firmware/v2.bin")]

def test_trigger_ota_logs_error_when_flash_runner_fails(caplog):
    link = HardwareEsp32Link(
        transport=_FakeTransport(), port="/dev/fake", flash_runner=lambda port, path: False
    )

    with caplog.at_level("ERROR"):
        link.trigger_ota("/firmware/v2.bin")

    assert any("flash failed" in record.message for record in caplog.records)
```

- [ ] **Step 2: Run the tests and verify they fail**

Run (from `pathfinder-autonomous/pi-mission/`): `pytest tests/test_hardware_esp32_link.py -v`
Expected: FAIL — `ModuleNotFoundError: No module named 'papaya_mission.hardware_esp32_link'`

- [ ] **Step 3: Write the implementation**

```python
# pathfinder-autonomous/pi-mission/papaya_mission/hardware_esp32_link.py
"""Real Esp32Link implementation over the Pi<->ESP32 UART link -- see
design spec: docs/superpowers/specs/2026-09-30-breadboard-bench-rig-design.md.

Message framing is newline-delimited JSON. The ESP32 pushes a heartbeat
(halted flag + throttle) roughly every 150ms plus an eager bump message
the instant one occurs -- this driver never blocks waiting for a reply,
it just drains whatever has arrived on the transport each time a
Protocol method is called and serves the request from cached state.

The transport and flash-runner are both injected via the constructor so
every line of protocol logic here is testable without a real serial port
or a real ESP32. Constructing the real pyserial-backed transport, and
invoking a real esptool.py flash against real hardware, are bench-time
work -- not built here.
"""
from __future__ import annotations

import json
import logging
import subprocess
from dataclasses import dataclass, field
from datetime import datetime, timezone
from typing import Protocol

from papaya_mission.esp32_link import BumpEvent, DriveStatus, Esp32Status

logger = logging.getLogger("papaya_mission.hardware_esp32_link")

class HardwareTransport(Protocol):
    """Duck-typed shape of the Pi<->ESP32 serial link this driver needs.
    `readline()` must return b"" (not block) when nothing new has
    arrived yet -- matching pyserial's own non-blocking-timeout mode,
    not its default blocking behavior.
    """

    def readline(self) -> bytes: ...
    def write(self, data: bytes) -> None: ...

class FlashRunner(Protocol):
    """Invokes esptool.py against the given port with the given firmware
    file, returning True on success.
    """

    def __call__(self, port: str, firmware_path: str) -> bool: ...

def _default_flash_runner(port: str, firmware_path: str) -> bool:
    result = subprocess.run(
        ["esptool.py", "--port", port, "write_flash", "0x10000", firmware_path],
        capture_output=True,
    )
    return result.returncode == 0

@dataclass
class HardwareEsp32Link:
    """Real Esp32Link implementation. This driver does not own exclusive
    access to `port` itself (the caller's transport does) -- trigger_ota()
    expects the caller to release/close the transport's hold on the port
    before calling it, and reopen it afterward, since esptool needs the
    port free. See the design spec's OTA section for the full mechanism.
    """

    transport: HardwareTransport
    port: str
    flash_runner: FlashRunner = _default_flash_runner
    _pending_bump_events: list[BumpEvent] = field(default_factory=list)
    _halted_on_contact: bool = False
    _last_throttle: float = 0.0
    geofence_updates_sent: list[list[str]] = field(default_factory=list)
    ota_triggers: list[str] = field(default_factory=list)

    def _drain_transport(self) -> None:
        while True:
            line = self.transport.readline()
            if not line:
                break
            self._handle_line(line)

    def _handle_line(self, line: bytes) -> None:
        try:
            message = json.loads(line.decode("utf-8").strip())
        except (ValueError, UnicodeDecodeError):
            logger.warning("Malformed line from ESP32: %r", line, exc_info=True)
            return
        message_type = message.get("type")
        if message_type == "bump":
            self._pending_bump_events.append(BumpEvent(detected_at=datetime.now(timezone.utc)))
        elif message_type == "status":
            self._halted_on_contact = bool(message.get("halted", False))
            self._last_throttle = float(message.get("throttle", 0.0))
        else:
            logger.warning("Unknown message type from ESP32: %r", message_type)

    def poll_bump_events(self) -> list[BumpEvent]:
        self._drain_transport()
        events, self._pending_bump_events = self._pending_bump_events, []
        return events

    def status(self) -> Esp32Status:
        self._drain_transport()
        return Esp32Status(halted_on_contact=self._halted_on_contact)

    def read_drive_status(self) -> DriveStatus:
        self._drain_transport()
        return DriveStatus(servo_positions_deg={}, throttle_position=self._last_throttle)

    def send_geofence_update(self, exclusion_zone_ids: list[str]) -> None:
        self.geofence_updates_sent.append(exclusion_zone_ids)
        line = json.dumps({"type": "geofence_update", "zone_ids": exclusion_zone_ids}) + "\n"
        self.transport.write(line.encode("utf-8"))

    def trigger_ota(self, firmware_path: str) -> None:
        self.ota_triggers.append(firmware_path)
        success = self.flash_runner(self.port, firmware_path)
        if not success:
            logger.error("esptool flash failed for %s on %s", firmware_path, self.port)
```

- [ ] **Step 4: Run the tests and verify they pass**

Run: `pytest tests/test_hardware_esp32_link.py -v`
Expected: PASS (9 passed)

- [ ] **Step 5: Commit**

```bash
git add pathfinder-autonomous/pi-mission/papaya_mission/hardware_esp32_link.py pathfinder-autonomous/pi-mission/tests/test_hardware_esp32_link.py
git commit -m "feat(pi-mission): add hardware Esp32Link driver over injected UART transport"
```

---

### Task 2: GPS + IMU hardware sensor sources

**Files:**
- Create: `pathfinder-autonomous/pi-mission/papaya_mission/hardware_sensor_hub.py`
- Test: `pathfinder-autonomous/pi-mission/tests/test_hardware_sensor_hub.py`

**Interfaces:**
- Consumes: `papaya_mission.position_fusion.{GpsFix, ImuReading}` (unchanged).
- Produces: `GpsLineSource` (`Protocol`: `readline() -> bytes`), `HardwareGpsSource(line_source: GpsLineSource, clock: Callable[[], float] = time.monotonic)` implementing `GpsSource`; `Bno055Device` (`Protocol`: `.euler -> tuple[float|None, float|None, float|None]`, `.linear_acceleration -> tuple[float|None, float|None, float|None]`), `HardwareImuSource(device: Bno055Device, clock: Callable[[], float] = time.monotonic)` implementing `ImuSource`. Task 3 adds `HardwareUltrasonicSource`/`HardwareCameraSource`/`HardwareSensorHub` to this same file.

- [ ] **Step 1: Write the failing tests**

```python
# pathfinder-autonomous/pi-mission/tests/test_hardware_sensor_hub.py
import math

from papaya_mission.hardware_sensor_hub import HardwareGpsSource, HardwareImuSource

# A real GGA sentence: fix quality 1, HDOP 1.2, lat 38 29.3754' N, lon 85 45.1234' W
_GGA_FIX = b"$GPGGA,123519,3829.3754,N,08545.1234,W,1,08,1.2,10.0,M,-34.2,M,,*6A\n"
_GGA_NO_FIX = b"$GPGGA,123519,,,,,0,00,99.9,,,,,,,*66\n"

def test_gps_returns_none_with_no_lines_available():
    source = HardwareGpsSource(line_source=_FakeLineSource([]), clock=lambda: 1.0)

    assert source.read() is None

def test_gps_parses_a_valid_gga_fix():
    source = HardwareGpsSource(line_source=_FakeLineSource([_GGA_FIX]), clock=lambda: 1.0)

    fix = source.read()

    assert fix is not None
    assert math.isclose(fix.lat, 38.0 + 29.3754 / 60.0, abs_tol=1e-6)
    assert math.isclose(fix.lon, -(85.0 + 45.1234 / 60.0), abs_tol=1e-6)
    assert math.isclose(fix.accuracy_m, 1.2 * 5.0, rel_tol=1e-6)
    assert fix.timestamp == 1.0

def test_gps_ignores_a_no_fix_sentence():
    source = HardwareGpsSource(line_source=_FakeLineSource([_GGA_NO_FIX]), clock=lambda: 1.0)

    assert source.read() is None

def test_gps_keeps_the_freshest_fix_when_multiple_lines_arrived():
    second_fix = b"$GPGGA,123520,3830.0000,N,08545.1234,W,1,08,1.0,10.0,M,-34.2,M,,*6B\n"
    source = HardwareGpsSource(line_source=_FakeLineSource([_GGA_FIX, second_fix]), clock=lambda: 2.0)

    fix = source.read()

    assert math.isclose(fix.lat, 38.0 + 30.0000 / 60.0, abs_tol=1e-6)

def test_gps_ignores_malformed_lines():
    source = HardwareGpsSource(line_source=_FakeLineSource([b"garbage\n", _GGA_FIX]), clock=lambda: 1.0)

    assert source.read() is not None

class _FakeLineSource:
    def __init__(self, lines: list[bytes]):
        self._lines = list(lines)

    def readline(self) -> bytes:
        if self._lines:
            return self._lines.pop(0)
        return b""

class _FakeBno055Device:
    def __init__(self, euler=(None, None, None), linear_acceleration=(None, None, None)):
        self.euler = euler
        self.linear_acceleration = linear_acceleration

def test_imu_returns_default_reading_before_any_valid_read():
    source = HardwareImuSource(device=_FakeBno055Device(), clock=lambda: 1.0)

    reading = source.read()

    assert reading.heading_deg == 0.0
    assert reading.forward_acceleration_mps2 == 0.0

def test_imu_reads_heading_and_forward_acceleration():
    device = _FakeBno055Device(euler=(90.0, 1.0, 2.0), linear_acceleration=(0.1, 0.5, -9.8))
    source = HardwareImuSource(device=device, clock=lambda: 3.0)

    reading = source.read()

    assert reading.heading_deg == 90.0
    assert reading.forward_acceleration_mps2 == 0.5
    assert reading.timestamp == 3.0

def test_imu_returns_last_known_reading_when_device_reports_none():
    device = _FakeBno055Device(euler=(45.0, 0.0, 0.0), linear_acceleration=(0.0, 1.0, 0.0))
    source = HardwareImuSource(device=device, clock=lambda: 1.0)
    first = source.read()

    device.euler = (None, None, None)
    device.linear_acceleration = (None, None, None)
    second = source.read()

    assert second == first
```

- [ ] **Step 2: Run the tests and verify they fail**

Run: `pytest tests/test_hardware_sensor_hub.py -v`
Expected: FAIL — `ModuleNotFoundError: No module named 'papaya_mission.hardware_sensor_hub'`

- [ ] **Step 3: Write the implementation**

```python
# pathfinder-autonomous/pi-mission/papaya_mission/hardware_sensor_hub.py
"""Real SensorHub implementations for the breadboard bench rig -- see
design spec: docs/superpowers/specs/2026-09-30-breadboard-bench-rig-design.md.

Every hardware dependency (a serial-like line source, an I2C IMU device,
a GPIO pulse timer, a camera classifier) is injected via the
constructor and typed against a Protocol defined in this file, never a
real hardware library -- see each class's docstring. Constructing the
real hardware objects (pyserial, pigpio, adafruit-blinka/BNO055,
picamera2/IMX500) is bench-time work, not built here.
"""
from __future__ import annotations

import time
from typing import Callable, Protocol

from papaya_mission.position_fusion import GpsFix, ImuReading

class GpsLineSource(Protocol):
    """Duck-typed shape of the GPS's serial link. readline() must return
    b"" (not block) when nothing new has arrived -- same convention as
    HardwareEsp32Link's transport.
    """

    def readline(self) -> bytes: ...

def _nmea_coord_to_decimal(value: str, hemisphere: str) -> float | None:
    if not value:
        return None
    dot = value.index(".")
    degrees = int(value[: dot - 2])
    minutes = float(value[dot - 2 :])
    decimal = degrees + minutes / 60.0
    if hemisphere in ("S", "W"):
        decimal = -decimal
    return decimal

def _parse_gga(line: str, timestamp: float) -> GpsFix | None:
    if "GGA" not in line:
        return None
    body = line.split("*")[0]
    fields = body.split(",")
    if len(fields) < 9:
        return None
    try:
        fix_quality = int(fields[6]) if fields[6] else 0
        if fix_quality == 0:
            return None
        lat = _nmea_coord_to_decimal(fields[2], fields[3])
        lon = _nmea_coord_to_decimal(fields[4], fields[5])
        hdop = float(fields[8]) if fields[8] else 99.0
    except (ValueError, IndexError):
        return None
    if lat is None or lon is None:
        return None
    # Rough accuracy estimate: HDOP * typical SBAS-corrected UERE (~5m).
    # Refine once real-world fix data is available from bench testing.
    accuracy_m = hdop * 5.0
    return GpsFix(lat=lat, lon=lon, accuracy_m=accuracy_m, timestamp=timestamp)

class HardwareGpsSource:
    def __init__(self, line_source: GpsLineSource, clock: Callable[[], float] = time.monotonic) -> None:
        self._line_source = line_source
        self._clock = clock

    def read(self) -> GpsFix | None:
        fix: GpsFix | None = None
        while True:
            raw = self._line_source.readline()
            if not raw:
                break
            try:
                line = raw.decode("ascii", errors="ignore").strip()
            except UnicodeDecodeError:
                continue
            parsed = _parse_gga(line, self._clock())
            if parsed is not None:
                fix = parsed
        return fix

class Bno055Device(Protocol):
    """Duck-typed shape of an Adafruit CircuitPython BNO055 device
    object. Both properties return (None, None, None) when a fresh
    reading isn't currently available (e.g. not yet calibrated).
    """

    @property
    def euler(self) -> tuple[float | None, float | None, float | None]: ...
    @property
    def linear_acceleration(self) -> tuple[float | None, float | None, float | None]: ...

class HardwareImuSource:
    """Axis choice for forward acceleration (the second/Y element of
    linear_acceleration) assumes a specific physical mounting
    orientation -- confirm once physically mounted and adjust the index
    if the sign/axis turns out wrong.
    """

    def __init__(self, device: Bno055Device, clock: Callable[[], float] = time.monotonic) -> None:
        self._device = device
        self._clock = clock
        self._last_reading = ImuReading(heading_deg=0.0, forward_acceleration_mps2=0.0, timestamp=0.0)

    def read(self) -> ImuReading:
        heading, _roll, _pitch = self._device.euler
        _ax, forward_accel, _az = self._device.linear_acceleration
        if heading is None or forward_accel is None:
            return self._last_reading
        reading = ImuReading(
            heading_deg=heading % 360.0,
            forward_acceleration_mps2=forward_accel,
            timestamp=self._clock(),
        )
        self._last_reading = reading
        return reading
```

- [ ] **Step 4: Run the tests and verify they pass**

Run: `pytest tests/test_hardware_sensor_hub.py -v`
Expected: PASS (8 passed)

- [ ] **Step 5: Commit**

```bash
git add pathfinder-autonomous/pi-mission/papaya_mission/hardware_sensor_hub.py pathfinder-autonomous/pi-mission/tests/test_hardware_sensor_hub.py
git commit -m "feat(pi-mission): add hardware GPS (NMEA GGA) and IMU (BNO055) sensor sources"
```

---

### Task 3: Ultrasonic + camera hardware sources, and the bundled SensorHub

**Files:**
- Modify: `pathfinder-autonomous/pi-mission/papaya_mission/hardware_sensor_hub.py`
- Modify: `pathfinder-autonomous/pi-mission/tests/test_hardware_sensor_hub.py`

**Interfaces:**
- Consumes: `papaya_mission.sensor_hub.ObstacleDetection` (unchanged); `HardwareGpsSource`, `HardwareImuSource` from Task 2.
- Produces: `PulseMeasurer` (`Protocol`: `measure_echo_pulse_us() -> float | None`), `HardwareUltrasonicSource(pulse_measurer: PulseMeasurer)` implementing `UltrasonicSource`; `ClassifierSource` (`Protocol`: `classify() -> tuple[str, float] | None`), `HardwareCameraSource(classifier_source: ClassifierSource)` implementing `CameraSource`; `HardwareSensorHub(gps, imu, ultrasonic, camera)` bundling all four into one `SensorHub`-conforming object. Task 5 passes a `HardwareSensorHub` instance straight to `MissionRuntime(sensor_hub=...)`.

- [ ] **Step 1: Write the failing tests**

Append to `test_hardware_sensor_hub.py`:

```python
from papaya_mission.hardware_sensor_hub import (
    HardwareCameraSource,
    HardwareSensorHub,
    HardwareUltrasonicSource,
)

class _FakePulseMeasurer:
    def __init__(self, pulse_us: float | None) -> None:
        self._pulse_us = pulse_us

    def measure_echo_pulse_us(self) -> float | None:
        return self._pulse_us

def test_ultrasonic_returns_none_when_no_echo():
    source = HardwareUltrasonicSource(pulse_measurer=_FakePulseMeasurer(None))

    assert source.read() is None

def test_ultrasonic_converts_pulse_width_to_range_with_zero_bearing():
    # Standard HC-SR04 formula: distance_cm = pulse_width_us / 58.0.
    # 580us / 58.0 = 10cm = 0.1m.
    source = HardwareUltrasonicSource(pulse_measurer=_FakePulseMeasurer(580.0))

    detection = source.read()

    assert detection is not None
    assert detection.relative_bearing_deg == 0.0
    assert detection.range_m == 0.1

class _FakeClassifierSource:
    def __init__(self, result: tuple[str, float] | None) -> None:
        self._result = result

    def classify(self) -> tuple[str, float] | None:
        return self._result

def test_camera_returns_none_when_nothing_classified():
    source = HardwareCameraSource(classifier_source=_FakeClassifierSource(None))

    assert source.read() is None

def test_camera_passes_through_a_classification():
    source = HardwareCameraSource(classifier_source=_FakeClassifierSource(("barrel", 0.9)))

    assert source.read() == ("barrel", 0.9)

def test_hardware_sensor_hub_bundles_all_four_sources():
    gps = HardwareGpsSource(line_source=_FakeLineSource([]), clock=lambda: 1.0)
    imu = HardwareImuSource(device=_FakeBno055Device(), clock=lambda: 1.0)
    ultrasonic = HardwareUltrasonicSource(pulse_measurer=_FakePulseMeasurer(None))
    camera = HardwareCameraSource(classifier_source=_FakeClassifierSource(None))

    hub = HardwareSensorHub(gps=gps, imu=imu, ultrasonic=ultrasonic, camera=camera)

    assert hub.gps is gps
    assert hub.imu is imu
    assert hub.ultrasonic is ultrasonic
    assert hub.camera is camera
```

- [ ] **Step 2: Run the tests and verify they fail**

Run: `pytest tests/test_hardware_sensor_hub.py -v`
Expected: FAIL — `ImportError: cannot import name 'HardwareUltrasonicSource'` (and similarly for `HardwareCameraSource`/`HardwareSensorHub`)

- [ ] **Step 3: Write the implementation**

Add to `hardware_sensor_hub.py`'s imports:

```python
from papaya_mission.sensor_hub import ObstacleDetection
```

Append these classes to the file:

```python
class PulseMeasurer(Protocol):
    """Triggers the ultrasonic sensor and returns the echo pulse width
    in microseconds, or None if no echo was received (nothing in
    range). The real implementation (a pigpio-timed TRIG/ECHO sequence
    through the voltage divider) is bench-time work.
    """

    def measure_echo_pulse_us(self) -> float | None: ...

class HardwareUltrasonicSource:
    """The bench rig has no mast-rotation servo wired (see
    docs/wiring/breadboard-wiring-layout.yaml) -- the sensor is simply
    forward-facing, so relative_bearing_deg is always 0.0 here.
    """

    def __init__(self, pulse_measurer: PulseMeasurer) -> None:
        self._pulse_measurer = pulse_measurer

    def read(self) -> ObstacleDetection | None:
        pulse_us = self._pulse_measurer.measure_echo_pulse_us()
        if pulse_us is None:
            return None
        range_m = (pulse_us / 58.0) / 100.0
        return ObstacleDetection(relative_bearing_deg=0.0, range_m=range_m)

class ClassifierSource(Protocol):
    """Returns the current camera classification, or None if nothing is
    classified this read. The real Pi AI Camera / picamera2 / IMX500
    backend is bench-time work -- its API is fast-moving and best
    confirmed against the actual camera and current docs, not guessed
    at here. Any real implementation that satisfies this shape drops in
    without changing HardwareCameraSource.
    """

    def classify(self) -> tuple[str, float] | None: ...

class HardwareCameraSource:
    def __init__(self, classifier_source: ClassifierSource) -> None:
        self._classifier_source = classifier_source

    def read(self) -> tuple[str, float] | None:
        return self._classifier_source.classify()

class HardwareSensorHub:
    def __init__(self, gps, imu, ultrasonic, camera) -> None:
        self.gps = gps
        self.imu = imu
        self.ultrasonic = ultrasonic
        self.camera = camera
```

- [ ] **Step 4: Run the tests and verify they pass**

Run: `pytest tests/test_hardware_sensor_hub.py -v`
Expected: PASS (13 passed)

- [ ] **Step 5: Commit**

```bash
git add pathfinder-autonomous/pi-mission/papaya_mission/hardware_sensor_hub.py pathfinder-autonomous/pi-mission/tests/test_hardware_sensor_hub.py
git commit -m "feat(pi-mission): add hardware ultrasonic/camera sources and bundle HardwareSensorHub"
```

---

### Task 4: LCD status display

**Files:**
- Create: `pathfinder-autonomous/pi-mission/papaya_mission/status_display.py`
- Test: `pathfinder-autonomous/pi-mission/tests/test_status_display.py`

**Interfaces:**
- Consumes: nothing from earlier tasks (independent of the sensor/link drivers — it reads a plain `dict[str, Any]` state snapshot, the same shape as what feeds `build_telemetry_record`).
- Produces: `LcdWriter` (`Protocol`: `write_lines(line1: str, line2: str) -> None`), `Screen` (frozen dataclass: `name: str`, `render: Callable[[dict], tuple[str, str]]`, `function_actions: dict[int, Callable[[dict], None]]`), `DEFAULT_SCREENS: list[Screen]`, `StatusDisplay(lcd: LcdWriter, screens: list[Screen] | None = None)` with `.current_screen`, `.next_screen()`, `.previous_screen()`, `.press_function_button(index: int, state: dict)`, `.refresh(state: dict)`.

- [ ] **Step 1: Write the failing tests**

```python
# pathfinder-autonomous/pi-mission/tests/test_status_display.py
from papaya_mission.status_display import Screen, StatusDisplay

class _FakeLcdWriter:
    def __init__(self) -> None:
        self.writes: list[tuple[str, str]] = []

    def write_lines(self, line1: str, line2: str) -> None:
        self.writes.append((line1, line2))

def _make_test_screens() -> list[Screen]:
    actions_taken = []
    return [
        Screen(name="a", render=lambda state: ("A1", "A2")),
        Screen(
            name="b",
            render=lambda state: ("B1", "B2"),
            function_actions={0: lambda state: actions_taken.append(("b", 0, state))},
        ),
    ], actions_taken

def test_starts_on_the_first_screen():
    screens, _ = _make_test_screens()
    display = StatusDisplay(lcd=_FakeLcdWriter(), screens=screens)

    assert display.current_screen.name == "a"

def test_next_screen_wraps_around():
    screens, _ = _make_test_screens()
    display = StatusDisplay(lcd=_FakeLcdWriter(), screens=screens)

    display.next_screen()
    assert display.current_screen.name == "b"
    display.next_screen()
    assert display.current_screen.name == "a"

def test_previous_screen_wraps_around():
    screens, _ = _make_test_screens()
    display = StatusDisplay(lcd=_FakeLcdWriter(), screens=screens)

    display.previous_screen()
    assert display.current_screen.name == "b"

def test_refresh_writes_the_current_screens_render_output():
    screens, _ = _make_test_screens()
    lcd = _FakeLcdWriter()
    display = StatusDisplay(lcd=lcd, screens=screens)

    display.refresh(state={})

    assert lcd.writes == [("A1", "A2")]

def test_refresh_truncates_lines_longer_than_16_characters():
    screens = [Screen(name="long", render=lambda state: ("A" * 20, "B" * 20))]
    lcd = _FakeLcdWriter()
    display = StatusDisplay(lcd=lcd, screens=screens)

    display.refresh(state={})

    line1, line2 = lcd.writes[0]
    assert len(line1) == 16
    assert len(line2) == 16

def test_function_button_dispatches_to_the_current_screens_action():
    screens, actions_taken = _make_test_screens()
    display = StatusDisplay(lcd=_FakeLcdWriter(), screens=screens)
    display.next_screen()  # move to screen "b", which has a function_actions[0]

    display.press_function_button(0, state={"key": "value"})

    assert actions_taken == [("b", 0, {"key": "value"})]

def test_function_button_with_no_action_for_that_index_does_nothing():
    screens, actions_taken = _make_test_screens()
    display = StatusDisplay(lcd=_FakeLcdWriter(), screens=screens)
    display.next_screen()  # screen "b" only has an action for index 0

    display.press_function_button(1, state={})

    assert actions_taken == []

def test_default_screens_render_without_raising_on_an_empty_state():
    from papaya_mission.status_display import DEFAULT_SCREENS

    for screen in DEFAULT_SCREENS:
        line1, line2 = screen.render({})
        assert isinstance(line1, str)
        assert isinstance(line2, str)
```

- [ ] **Step 2: Run the tests and verify they fail**

Run: `pytest tests/test_status_display.py -v`
Expected: FAIL — `ModuleNotFoundError: No module named 'papaya_mission.status_display'`

- [ ] **Step 3: Write the implementation**

```python
# pathfinder-autonomous/pi-mission/papaya_mission/status_display.py
"""LCD status display: a small set of screens cycled by up/down
buttons, with 2 function buttons whose meaning depends on the current
screen (soft-key style) -- see design spec:
docs/superpowers/specs/2026-09-30-breadboard-bench-rig-design.md.

Reads the same state MissionRuntime already assembles into telemetry
each tick -- no separate data path. The LCD write backend (the real
1602A/PCF8574 byte-banged protocol -- see github.com/UCTRONICS/KB0005
for the confirmed reference) is injected via the constructor, so every
screen/navigation/dispatch rule here is testable without a real LCD.
Building the real PCF8574 writer is bench-time work, not done here.
"""
from __future__ import annotations

from dataclasses import dataclass, field
from typing import Any, Callable, Protocol

class LcdWriter(Protocol):
    """Writes exactly two lines (already truncated to the display's
    width) to the physical LCD.
    """

    def write_lines(self, line1: str, line2: str) -> None: ...

@dataclass(frozen=True)
class Screen:
    name: str
    render: Callable[[dict[str, Any]], tuple[str, str]]
    # Maps function-button index (0 or 1) to an action taken on press.
    # A screen with no entry for a given index does nothing on that
    # button -- not every screen needs to use both function buttons.
    function_actions: dict[int, Callable[[dict[str, Any]], None]] = field(default_factory=dict)

def _render_position(state: dict[str, Any]) -> tuple[str, str]:
    position = state.get("position")
    heading = state.get("heading_deg")
    if position is None or heading is None:
        return ("GPS: no fix", "")
    lon, lat = position
    return (f"{lat:.5f},{lon:.5f}", f"Hdg {heading:.0f} deg")

def _render_mission(state: dict[str, Any]) -> tuple[str, str]:
    alert = state.get("mission_alert") or "none"
    nav_mode = state.get("nav_mode", "idle")
    return (f"Mode: {nav_mode}", f"Alert: {alert}")

def _render_obstacles(state: dict[str, Any]) -> tuple[str, str]:
    count = state.get("obstacle_count", 0)
    last_type = state.get("last_obstacle_type", "-")
    return (f"Obstacles: {count}", f"Last: {last_type}")

def _render_drive(state: dict[str, Any]) -> tuple[str, str]:
    throttle = state.get("throttle_position", 0.0)
    halted = state.get("halted_on_contact", False)
    return (f"Throttle: {throttle:.2f}", "HALTED" if halted else "running")

DEFAULT_SCREENS: list[Screen] = [
    Screen(name="position", render=_render_position),
    Screen(name="mission", render=_render_mission),
    Screen(name="obstacles", render=_render_obstacles),
    Screen(name="drive", render=_render_drive),
]

class StatusDisplay:
    def __init__(self, lcd: LcdWriter, screens: list[Screen] | None = None) -> None:
        self._lcd = lcd
        self._screens = screens if screens is not None else DEFAULT_SCREENS
        self._index = 0

    @property
    def current_screen(self) -> Screen:
        return self._screens[self._index]

    def next_screen(self) -> None:
        self._index = (self._index + 1) % len(self._screens)

    def previous_screen(self) -> None:
        self._index = (self._index - 1) % len(self._screens)

    def press_function_button(self, index: int, state: dict[str, Any]) -> None:
        action = self.current_screen.function_actions.get(index)
        if action is not None:
            action(state)

    def refresh(self, state: dict[str, Any]) -> None:
        line1, line2 = self.current_screen.render(state)
        self._lcd.write_lines(line1[:16], line2[:16])
```

- [ ] **Step 4: Run the tests and verify they pass**

Run: `pytest tests/test_status_display.py -v`
Expected: PASS (8 passed)

- [ ] **Step 5: Commit**

```bash
git add pathfinder-autonomous/pi-mission/papaya_mission/status_display.py pathfinder-autonomous/pi-mission/tests/test_status_display.py
git commit -m "feat(pi-mission): add LCD status display with screen navigation and soft-key dispatch"
```

---

### Task 5: End-to-end wiring against a real MissionRuntime

**Files:**
- Create: `pathfinder-autonomous/pi-mission/tests/test_hardware_drivers_integration.py`

**Interfaces:**
- Consumes: `HardwareSensorHub`, `HardwareGpsSource`, `HardwareImuSource`, `HardwareUltrasonicSource`, `HardwareCameraSource` from Tasks 2-3; `HardwareEsp32Link` from Task 1; `papaya_mission.runtime.MissionRuntime`. Follows the same `_make_started_runtime` fixture pattern as `tests/test_runtime_tick_sensing.py` and `tests/test_digital_twin_scenarios.py`.
- Produces: nothing consumed by later tasks — this is the final task in the plan.

- [ ] **Step 1: Write the failing tests**

```python
# pathfinder-autonomous/pi-mission/tests/test_hardware_drivers_integration.py
import httpx

from papaya_mission.hardware_esp32_link import HardwareEsp32Link
from papaya_mission.hardware_sensor_hub import (
    HardwareCameraSource,
    HardwareGpsSource,
    HardwareImuSource,
    HardwareSensorHub,
    HardwareUltrasonicSource,
)
from papaya_mission.runtime import MissionRuntime

FIELD_RING = [[-85.10, 38.00], [-85.10, 38.10], [-84.90, 38.10], [-84.90, 38.00], [-85.10, 38.00]]

class _FakeLineSource:
    def readline(self) -> bytes:
        return b""

class _FakeBno055Device:
    euler = (0.0, 0.0, 0.0)
    linear_acceleration = (0.0, 0.0, 0.0)

class _FakePulseMeasurer:
    def measure_echo_pulse_us(self):
        return None

class _FakeClassifierSource:
    def classify(self):
        return None

class _FakeTransport:
    def readline(self) -> bytes:
        return b""

    def write(self, data: bytes) -> None:
        pass

def _handler(rover, geofences):
    def handler(request: httpx.Request) -> httpx.Response:
        if request.url.path == "/rovers/rover-1":
            return httpx.Response(200, json=rover)
        if request.url.path == "/geofences":
            return httpx.Response(200, json=geofences)
        if request.url.path.startswith("/geofences/"):
            fid = request.url.path.rsplit("/", 1)[-1]
            return httpx.Response(200, json=next(g for g in geofences if g["_id"] == fid))
        raise AssertionError(request.url.path)

    return handler

def test_assembled_hardware_drivers_satisfy_protocols_and_tick_cleanly(tmp_path):
    sensor_hub = HardwareSensorHub(
        gps=HardwareGpsSource(line_source=_FakeLineSource()),
        imu=HardwareImuSource(device=_FakeBno055Device()),
        ultrasonic=HardwareUltrasonicSource(pulse_measurer=_FakePulseMeasurer()),
        camera=HardwareCameraSource(classifier_source=_FakeClassifierSource()),
    )
    esp32_link = HardwareEsp32Link(transport=_FakeTransport(), port="/dev/fake")

    rover = {"_id": "rover-1", "name": "George", "length_m": 0.6, "turn_style": "spin_in_place"}
    inclusive = {"_id": "fence-1", "type": "inclusive", "boundary": {"type": "Polygon", "coordinates": [FIELD_RING]}}
    client = httpx.Client(transport=httpx.MockTransport(_handler(rover, [inclusive])))

    runtime = MissionRuntime(
        rover_id="rover-1",
        backend_base_url="http://backend.local",
        local_db_path=str(tmp_path / "test.db"),
        sensor_hub=sensor_hub,
        esp32_link=esp32_link,
        http_client=client,
    )
    runtime.startup()
    runtime.handle_start_sweep({"geofence_id": "fence-1"})

    for _ in range(3):
        runtime.tick()  # must not raise; no GPS fix is ever scripted from the fakes

    # Matches the existing, already-tested "never acquired a real fix" behavior
    # (see test_gps_never_acquired_still_triggers_stop_and_alert in
    # test_runtime_tick_sensing.py): the dummy-seed error radius already
    # exceeds GPS_LOSS_MAX_ERROR_RADIUS_M from tick 1, so this is deterministic,
    # not merely one possible outcome among several.
    assert runtime.mission_alert == "gps_stop_and_alert"
```

- [ ] **Step 2: Run the tests and verify they pass**

Run: `pytest tests/test_hardware_drivers_integration.py -v`
Expected: PASS — this task adds no new production code, only a test exercising Tasks 1-4's classes against a real `MissionRuntime`. Treat an unexpected failure here as a real integration bug to fix, not a step to skip.

- [ ] **Step 3: (No new implementation)**

This task only proves the four driver classes genuinely satisfy `SensorHub`/`Esp32Link` and that `MissionRuntime` ticks cleanly against them — the same role `tests/test_digital_twin_scenarios.py` played for the digital twin.

- [ ] **Step 4: Run the full test suite and verify everything passes**

Run: `pytest -v` (from `pathfinder-autonomous/pi-mission/`)
Expected: PASS — all prior tests plus this plan's new ones (9 + 8 + 5 + 8 + 1 = 31 new tests).

- [ ] **Step 5: Commit**

```bash
git add pathfinder-autonomous/pi-mission/tests/test_hardware_drivers_integration.py
git commit -m "test(pi-mission): add end-to-end hardware-driver integration test against MissionRuntime"
```

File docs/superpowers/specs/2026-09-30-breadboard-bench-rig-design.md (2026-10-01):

# Breadboard Bench Rig — Design Notes

*Approved 2026-09-30.*

**Motivation:** before committing to a full PCB respin, validate real
sensor/firmware interplay on a breadboard — not full drive mode, just
whether the chosen sensors, the Pi-ESP32 link, and the existing
`papaya_mission` software actually work together on real hardware. This is
the second of two supporting pieces the user wanted before the ESP32
firmware plan (the first, the digital-twin simulator, is merged) — see
project memory `project-esp32-testing-strategy`.

## Decisions made so far

| Question | Decision |
|---|---|
| ESP32 unit | A separate, dedicated spare ESP32-S3 dev board — not the real Phase 1 rover's unit. Zero risk to the working build; new firmware written from scratch, nothing shared with the real rover's firmware. |
| ESP32 scope this pass | Included, not deferred: bump sensor(s) + I2C GPIO-expander + a first real Pi↔ESP32 link, directly serving "informs the real wire protocol." |
| Pi↔ESP32 link medium | UART — already implied by the approved OTA design ("the Pi flashes the ESP32 over the existing serial link using the same protocol a USB-connected laptop uses today," i.e. esptool-class flashing, which is inherently UART). |
| Software scope | Real `SensorHub`/`Esp32Link` Protocol-conforming drivers, run through the actual, already-tested `MissionRuntime` — the same role `SimulatedSensorHub` and the digital twin played, now backed by real hardware. Not throwaway bring-up scripts. |
| Compute | Raspberry Pi 5 (4GB or 8GB, both on hand), NVMe HAT available. Owns all sensing (GPS/IMU/ultrasonic/camera) + mission logic, per D-6. |
| Camera | Raspberry Pi AI Camera (v1 confirmed on hand), CSI connector, no GPIO. |
| Ultrasonic | 4Tronix-mast-bundled HC-SR04-class unit. Pi-managed via GPIO trigger/echo + `pigpio`. **ECHO is 5V — requires a 2-resistor voltage divider (1k/2k) before reaching the Pi GPIO; never direct.** |
| GPS | SparkFun NEO-M9N (SMA), wired via its **UART** pins (not its Qwiic/I2C option) — validates the intended long-term interface and keeps GPS traffic off the IMU/LCD I2C bus. |
| IMU | Wired **one at a time**, not simultaneously: Adafruit BNO055 active/first (onboard fusion → fastest path to a working `heading_deg`); SparkFun ICM-20948 documented as a direct swap-in (same 4 points) for comparison. Both NRND parts — fine for this bench eval, not the permanent PCB (see `feedback-verify-part-lifecycle-before-purchase`). |
| LCD | Pi-managed, I2C. **Confirmed (2026-09-30):** 1602A 16x2 character LCD + PCF8574 backpack, addr `0x27`, powered at 5V — two backpack-equipped units physically on hand, matching `github.com/UCTRONICS/KB0005`'s reference driver exactly. Screens driven from the same state `MissionRuntime` already assembles into telemetry each tick. |
| LCD navigation | Up/down buttons cycle screens; 2 function buttons whose meaning depends on the current screen (soft-key style, not fixed). All 4 buttons wired to GND, debounced via the Pi's internal GPIO pull-ups (no external resistor). |
| Throttle simulator | A potentiometer into an ESP32 ADC pin, reported via `read_drive_status`, mapped to `0.0`–`1.0` (forward-only; the full `-1.0..1.0` reverse range is deferred, not needed to validate the round-trip). |
| Spare ELRS controller | **Explicitly excluded from this pass.** Nothing in `MissionRuntime` commands throttle today — it only reads `drive_status` — so human-driven ELRS input wouldn't exercise anything new; it would just re-prove ELRS decoding, which the real Phase 1 firmware already does. Relevant again once a real Pi→ESP32 autonomous drive-command channel exists and manual-override arbitration becomes a real design question (see the inbox note on manual override). |
| Bump sensors (bench) | 2 switches (left/right) via a PCF8574 I2C GPIO-expander on the ESP32's own I2C bus (separate from the Pi's). PCF8574's built-in weak pull-ups mean each switch wires directly to GND, no external resistor. INT line to an ESP32 interrupt-capable GPIO for immediate response. |
| Bump sensors (production, logged not decided) | Likely 4 axle corners, possibly also payload-bay corners — depends on whether SEN-1's ultrasonic vertical beam cone already covers that height. Plan: empirically map the real cone on this breadboard (move a target vertically at a few distances, record where detection drops out) rather than estimate from a datasheet. |
| ESP32 firmware toolchain | Arduino framework (`.ino`), matching the real Phase 1 firmware's own convention. |
| Pi↔ESP32 message pattern | Periodic heartbeat (~150ms: halted flag + throttle) + eager push the instant a bump occurs — not request/response. Commands from the Pi (geofence update, OTA trigger) are one-way, fire-and-forget; nothing in `Esp32Link`'s existing signatures expects a blocking reply. |
| Message format | Newline-delimited JSON, one `type` field per line. |
| OTA mechanism (this pass) | No custom firmware cooperation needed: standard ESP32 dev boards already auto-enter their bootloader via the USB-serial chip's DTR/RTS lines, which is exactly what `esptool.py` does automatically. `trigger_ota()` just releases the Pi's serial connection, shells out to `esptool.py` against that port, and reopens the connection once the board reboots. Proves the real mechanism (no cable swap) without an in-firmware OTA state machine. |
| OTA safety gating (logged, not built here) | "WiFi in range" is already structurally guaranteed (can't have a firmware file without having downloaded it over WiFi). "No mission underway": Pi-side `SweepSession`-active check is the straightforward answer; a true device-level veto conflicts with this pass's auto-reset OTA mechanism (nothing in firmware is consulted) and is deferred to the ESP32 firmware plan. |
| Driver testability | `hardware_sensor_hub.py`/`hardware_esp32_link.py` accept their low-level transport (serial/I2C object) as a constructor argument rather than constructing it internally, so message framing, the bump-event queue, cached status, pot-to-throttle mapping, LCD screen content, and button dispatch are all genuinely unit-testable (TDD, same as the rest of this codebase) against an in-memory fake transport. Only the thin real-I/O calls themselves fall outside that — verified by the bring-up checklist instead. |
| Power domains | Pi and ESP32 have independent power supplies (separate USB sources) but **must share a common ground** for the UART link to be reliable. |
| Breadboard 5V source | The Pi's own 5V GPIO pin — combined ultrasonic + LCD draw is well under 150mA, trivial against the Pi 5's supply budget. Scoped to this breadboard only; the real PCB will likely reuse the existing U2 UBEC 5V rail instead (a later decision, not in conflict — see `pathfinder/papaya-wiring-layout.yaml`'s `u2`). |
| Wiring-file convention | New `docs/wiring/` directory holds all non-"real rover" wiring snapshots, named descriptively (not version-numbered) — this breadboard first, future per-mission-package builds later. The root `papaya-wiring-layout.yaml` (real Phase 1 rover) is untouched; it's referenced by name in 3 KiCad generator scripts and 6 docs. `generate_schematic.py`/`sync_pin_names.py` already take `--yaml PATH` and work unmodified against any file following the same schema; `assign_footprints.py` is a Phase-1-specific one-off (hardcodes footprint content, not just paths) and isn't meant to generalize. |

## Architecture

Two physically separate units, each independently powered, tied together
by one UART link and a shared ground:

```
┌─────────────────────────┐         UART (TX/RX)        ┌──────────────────────────┐
│       Raspberry Pi 5      │◄───────────────────────────►│   ESP32-S3 dev board      │
│                           │         + shared GND         │   (bench-dedicated)       │
│  MissionRuntime           │                              │                           │
│   ├─ hardware_sensor_hub  │                              │  New firmware (.ino):     │
│   │   GPS (UART)          │                              │   - PCF8574 bump sensing  │
│   │   IMU (I2C)           │                              │     (I2C + INT)           │
│   │   Ultrasonic (GPIO +  │                              │   - Pot ADC read          │
│   │     pigpio, divider)  │                              │   - UART heartbeat/push   │
│   │   Camera (CSI)        │                              │   - halted-state LED      │
│   ├─ hardware_esp32_link  │                              │                           │
│   │   (UART, NDJSON)      │                              │  OTA: esptool's own       │
│   └─ status_display       │                              │  DTR/RTS auto-reset,      │
│       LCD + 4 buttons     │                              │  no firmware cooperation  │
│       (I2C + GPIO)        │                              │  needed this pass         │
└─────────────────────────┘                              └──────────────────────────┘
```

No custom PCB in this build — see `docs/wiring/breadboard-wiring-layout.yaml`
for the full pin-level netlist (17 components, cross-validated so every
connection references a real component/pin). The physical breadboard
placement diagram (which rows on which board, how to combine the 30-pin/
63-pin boards on hand) is a separate, later step, done only once every pin
assignment above is settled — so it only needs to be drawn once.
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

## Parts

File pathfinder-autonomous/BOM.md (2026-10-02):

# Papaya Pathfinder — Autonomous (Phase 2) BOM

Running parts tally for the `pathfinder-autonomous/` rebuild. Started
2026-09-24 during MP-1 planning. Companion to the Phase 1 BOM at
[`pathfinder/BOM.md`](../pathfinder/BOM.md), which stays as the
historical record for the original build — this file is Phase 2's own,
not a replacement.

## Status legend

| Status | Meaning |
|---|---|
| **Verified** | Purchased, in hand, measured/confirmed working (Phase 1 build) |
| **Purchased — Unverified** | In hand, but not yet confirmed equivalent/working |
| **On Hand — Design Pending** | Owned already, but not yet decided whether/how it's used |
| **Pending Selection** | Required or recommended for Phase 2; no specific part chosen yet |

Descriptive/requirements-only entries come first for anything still
`Pending Selection`; each gets amended with real ASIN/URL/measured
footprint once a part is actually bought, same discipline as the Phase 1
BOM.

---

## Reused from Phase 1 — Verified

Copied from [`pathfinder/BOM.md`](../pathfinder/BOM.md) — these are
expected to carry over into the Phase 2 build unchanged.

- **PCB Screw Terminal Assortment** — general screw terminal attachments.
  Amazon URL: https://www.amazon.com/dp/B0D1GMMTZ5?ref=ppx_yo2ov_dt_b_fed_asin_title&th=1
  Amazon ASIN: B0D1GMMTZ5
  Usage: Primary off-board connectors for incoming power and ground, plus
  connections from ESP32 to BTS motor controller signal connections. The
  BTS connections could be header pin based if needed to conserve board
  space.
  Footprint: Single connectors at approximately 5mm square, but can be
  combined into multiple component blocks at 5mm increments.

- **UBEC 5V/3A** — tagged as `U2`.
  Amazon URL: https://www.amazon.com/dp/B07PLSYX9G?ref=ppx_yo2ov_dt_b_fed_asin_title
  Amazon ASIN: B07PLSYX9G
  Footprint: rectangular with 4 pins at the corners, approx 10mm x 15mm.
  Input and output pins are on the 'short' sides.

- **UBEC 6V/8A** — tagged as `U1`.
  Amazon URL: https://www.amazon.com/dp/B07DD9L6P6?ref=ppx_yo2ov_dt_b_fed_asin_title
  Amazon ASIN: B07DD9L6P6
  Footprint: Off board. Connect output from U1 into screw terminals.

- **ESP32-S3 Development Board** — used for ESP32 footprint. Remains the
  real-time drive/servo/ELRS controller in the Phase 2 hybrid
  architecture (design spec: Architecture — "Why not consolidate onto
  one board").
  Amazon URL: https://www.amazon.com/dp/B0F5QCK6X5?ref=ppx_yo2ov_dt_b_fed_asin_title&th=1
  Amazon ASIN: B0F5QCK6X5
  Footprint: NOT a single 2x22 block -- two separate 1x22 P2.54mm header
  rows (Espressif calls them J1/J3). Measured row-to-row centerline
  spacing was 25.5-26.0mm; deliberately loosened to 25.40mm row spacing /
  2.0mm pad / 1.1mm drill for assembly tolerance rather than targeting
  the raw measurement exactly. Pin 1 of both rows is at the same end of
  the board; row orientation corrected after an initial mirrored build
  (J1-origin pins on the +Y row, J3-origin on -Y). Custom footprint:
  `pathfinder/kicad/papaya-pcb/papaya-pcb.pretty/ESP32S3_DevKit_2x1x22_split.kicad_mod`,
  pin assignment per Espressif's published ESP32-S3-DevKitC-1 J1/J3
  tables.

- **Other connectors** — standard header pins.
  - Servo connectors S1, S2, S3, S4: 3-pin male headers (black/red/white
    sequence)
  - Radio receiver connector J4: 4-pin male headers (Red/Black and
    Green/White)

## Reused from Phase 1 — Purchased, Unverified

- **ESP32-S3 Development Board (alternate stock)** — the original
  vendor listing (ASIN `B0F5QCK6X5` above) went out of stock after the
  last purchase. Backup inventory on hand from a different listing,
  claimed by the seller to be the same underlying board.
  Amazon URL: *(fill in when confirming — not yet recorded)*
  Amazon ASIN: *(different from `B0F5QCK6X5` — fill in)*
  **Needs verification before use:** confirm pinout/footprint actually
  matches the measured `ESP32S3_DevKit_2x1x22_split` footprint above
  before relying on it for a build — "purports to be the same
  component" isn't confirmed yet.

---

## On Hand — Design Decision Pending

Owned already; not yet decided whether Phase 2 actually uses them.

- **Raspberry Pi NVMe HAT + NVMe drive(s)** — not required for MP-1's
  own storage needs (obstacle list + telemetry are small — see the
  [design spec](../docs/superpowers/specs/2026-09-24-mp1-map-detect-explore-design.md)'s
  "Not in scope for MP-1"), but a real consideration for image/video
  retention: raw captures for low-confidence-classification debugging,
  and MP-2's chicken individual-ID reference image library, both
  plausibly need real storage volume beyond what's otherwise available.
  Not mandated yet — revisit before or alongside MP-2.

---

## New for Phase 2 — Confirmed, On Hand

Architecture/part decision made (see `docs/phase2/inputs/`); already
owned, no purchase needed.

- **Raspberry Pi 5** (4GB or 8GB, both on hand) — mission-logic/
  perception controller (D-6, Architecture: Compute split). Paired with
  the existing ESP32-S3, not replacing it. NVMe HAT also on hand, not
  required for MP-1's own storage but a candidate for image/video
  retention later (see "On Hand — Design Decision Pending" above).
  Amazon URL/ASIN: *(fill in from order history)*

- **Raspberry Pi AI Camera** — obstacle type classification (SEN-3),
  edge inference on-device. v1 unit on hand (confirmed, D-6); a v2 may
  also be on hand, unverified. A Pi HD Camera (non-AI) is also available
  as a fallback/secondary.
  Amazon URL/ASIN: *(fill in from order history)*

## New for Phase 2 — Purchased, Unverified

Specific SKU chosen and bought; not yet confirmed working on a real
bench.

- **GPS: SparkFun NEO-M9N (SMA variant)** — confirmed long-term pick
  (SEN-6, 2026-09-30): verified active/production, u-blox's own
  recommended migration target away from the NRND NEO-M8N, open
  schematics, panel-mount SMA for a separately-mounted antenna.
  **Needs a GPS-specific external antenna** — the SMA board has no
  onboard patch, and this hasn't been sourced yet.
  Amazon URL/ASIN: *(fill in from order history)*
  - Also on hand as a spare/fallback: **MicroAir M10G** — has an
    embedded 18×18×4mm patch antenna (no external antenna needed), plus
    a bundled QMC5883L magnetometer noted as a possible future IMU
    component (see IMU entry below).
    Amazon URL/ASIN: *(fill in from order history)*

- **IMU: Adafruit BNO055** (active) **and SparkFun ICM-20948** (swap-in
  alternate) — bought for breadboard bench evaluation (SEN-5,
  2026-09-30). **Both NRND — not for the permanent PCB.** BNO055 is
  NRND; ICM-20948 faces an imminent Last-Time-Delivery (~2026-10-30),
  AKM discontinuing the AK09916C magnetometer it depends on. TDK's
  suggested replacement path for the real build: ICM-42688-P/42670-P
  (6-axis) + a separate magnetometer (the MicroAir GPS board's bundled
  QMC5883L is a candidate). Still open — revisit before the PCB respin.
  Amazon URL/ASIN: *(fill in from order history, both parts)*

- **LCD: 1602A 16×2 character display + PCF8574 I2C backpack**
  (address `0x27`) — confirmed (COM-5, 2026-09-30), matches
  `github.com/UCTRONICS/KB0005`'s reference driver. Two backpack-
  equipped units on hand (one active, one spare), plus a third bare
  1602A (no backpack) as spare. Powered from the Pi's 5V pin.
  Amazon URL/ASIN: *(fill in from order history)*

---

## New for Phase 2 — Pending Selection

Everything below is required or recommended by the
[MP-1 design spec](../docs/superpowers/specs/2026-09-24-mp1-map-detect-explore-design.md)
but has no part chosen yet. No ASINs/URLs are included here — none
have been picked, so none are recorded.

- **Ultrasonic sensor** — mast-mounted, bearing + range obstacle
  detection (SEN-1). Starting candidate: the HC-SR04-class unit already
  bundled on the 4Tronix M.A.R.S. Rover mast, alongside its camera mount.

- **Bump sensors** — minimal set at the rover corners, wired to the
  ESP32 directly for zero-latency stop response (SEN-4, Sensing).
  Breadboard bench rig uses 2 (left/right) as a first pass; production
  count/placement (all 4 axle corners, possibly also payload-bay
  corners) still open — see SEN-4 in
  `docs/phase2/inputs/03-sensors-compute-electronics.md`.

- **I2C GPIO-expander: PCF8574** — confirmed for the breadboard (lets
  the 2 bump switches share one I2C bus plus an interrupt pin on the
  ESP32, instead of one dedicated pin per switch — the "bumper bus,"
  Architecture: Sensing/PCB impact). The LCD's backpack is also a
  PCF8574 at a different address (`0x27`), so no new chip-level part
  is needed beyond what the LCD already brought.

- **Battery-backed RTC module** — recommended addition (I2C, coin-cell
  backed, e.g. DS3231-class) so the Pi has a reasonable time reference
  immediately on a cold field boot, before GPS gets a fix. See
  [`docs/reference/time-synchronization.md`](../docs/reference/time-synchronization.md).

- **Mast** — evaluate reusing the 4tronix M.A.R.S. Rover mast (already
  integrates ultrasonic + a camera-class sensor + a small rotation
  servo) before committing to a custom design; confirm height/load
  specs are sufficient for this build's sensor payload (Architecture:
  Mast).

- **Pi ↔ ESP32 link hardware** — **confirmed: UART** (direct 3-wire
  GPIO, no cable), for vibration-resistance on a moving rover. Already
  wired this way on the breadboard (`docs/wiring/breadboard-wiring-layout.yaml`)
  and implemented in `hardware_esp32_link.py` (newline-delimited JSON
  over the UART transport).

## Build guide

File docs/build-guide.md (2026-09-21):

# Build Guide — From Scratch

A step-by-step path from "empty parts bin" to "driving under ELRS control,"
written after finishing Phase 1 of this build. Every step here exists
because something in that process either went wrong the first time or was
worth getting right before power was ever applied — see
[`docs/development-log.md`](development-log.md#phase-1-bring-up-2026-08-20--2026-09-19)
for the full narrative if you want the "why," and the
[Common pitfalls](#common-pitfalls-quick-reference) table at the end for a
condensed version.

This guide sequences and cross-links the existing detailed docs rather than
duplicating them — follow it in order, and follow the links when a step
says to.

## 1. Buy the parts

**On-board components** (things that mount directly to the custom PCB):
see [`pathfinder/BOM.md`](../pathfinder/BOM.md) for the exact parts
purchased, Amazon ASINs, and measured footprints — ESP32-S3 dev board,
both UBECs, screw terminals, header pins.

**Off-board system components**, not covered by the BOM (footprints for
these aren't on the PCB — they connect via the header/terminal
connectors the BOM does cover):

| Part | Model used in this build | Notes |
|---|---|---|
| Motor drivers | 2× BTS7960/IBT_2 | One per side |
| Drive motors | 6× GA25 DC gear motors | 3 ganged per side, one PWM signal per side |
| Steering servos | 4× Miuzei DS3218 (metal gear) | Rated 6–7.4V — matches the 6V servo bus by design |
| RC receiver | RadioMaster ELRS-RP3-V2 | 2.4GHz ELRS V3 |
| RC transmitter | BETAFPV LiteRadio 2 SE | 2.4GHz ELRS V3, Mode 2 |
| Battery | 3S LiPo | Feeds both UBECs directly |

If you substitute a different servo model, **check its rated voltage
before connecting it** — don't assume 6V is universally safe. Micro
servos (SG90/MG90S-class) are commonly rated only 4.8–6V, right at or
past the top of that range; metal-gear servos like the DS3218 above are
usually fine into the 6–7.4V range. When a servo has no printed spec,
look up the exact model/part number rather than guessing.

## 2. Get the PCB fabricated

The board is designed YAML-first —
[`papaya-wiring-layout.yaml`](../papaya-wiring-layout.yaml) is the system
source of truth, and the KiCad project at
[`pathfinder/kicad/papaya-pcb/`](../pathfinder/kicad/papaya-pcb/) is
generated/laid out from it. See
[`docs/development-log.md`](development-log.md) for the full design
narrative if you're starting a layout from scratch.

As of v2.0.1, the committed `.kicad_pcb` file already includes the
permanent servo-ground fix from [ADR 0002](adr/0002-servo-header-ground-isolation.md)
— boards fabricated from the current file don't need the hand-wired
jumper workaround in step 4 below. If you're working from an older copy
of the file (pre-2026-09-20), apply that fix first and re-verify with
`kicad-cli pcb drc --severity-all --schematic-parity` (expect 0
violations) **and** a visual copper-fill review in the KiCad GUI — a
clean DRC run alone was not sufficient to catch this defect the first
time.

OSH Park (or an equivalent fab) accepts the `.kicad_pcb` file directly, or
use the Gerbers already exported to
[`pathfinder/kicad/papaya-pcb/gerbers/`](../pathfinder/kicad/papaya-pcb/gerbers/)
(regenerate these if you change the design — `kicad-cli pcb export
gerbers` / `pcb export drill`).

## 3. Trim the ESP32 header pins

Before seating the ESP32-S3 module in its header, remove its GPIO15 and
GPIO40 pins (desolder/clip both the module's own pins and, if not already
excluded, the matching board socket pins). Neither pin is used by the
firmware. See [ADR 0001](adr/0001-esp32-header-pin-trimming.md) for why —
a copper pour boundary on this board passes close enough between those two
positions to risk an accidental short. The rest of the module's unused
header pins are left in place for mechanical retention.

## 4. Wire everything up

Wire per [`papaya-wiring-layout.yaml`](../papaya-wiring-layout.yaml) and
the pin tables in [`docs/elrs-wiring.md`](elrs-wiring.md). A few points
that caused real problems in this build, worth doing deliberately rather
than quickly:

- **Motor power distribution terminal block:** wire this carefully against
  the wiring diagram and double-check polarity and terminal positions
  before ever applying power. A miswired distribution block here shorted
  the motor supply during this build's first full bring-up — it looked
  like a dead motor driver, not a wiring mistake, until traced back.
- **Servo connectors:** match pins by **position**, not by wire color —
  color conventions vary between servo brands (e.g. brown vs. black for
  ground on different manufacturers). The reliable anchor is that power
  (red) is always the center pin of the 3-pin connector; ground and signal
  are the two outer pins, whichever colors your specific servo uses.
- **Servo ground jumpers (temporary, until a fixed board is fabricated):**
  if you're building on a board fabricated before ADR 0002's permanent fix
  is applied, run one wire per servo connector from `J8`'s ground terminal
  directly to that connector's `GND` pin — soldered, not just clipped on,
  and one wire per connector rather than daisy-chained. Without this, all
  four servos will be completely unresponsive despite everything else
  working correctly. See [ADR 0002](adr/0002-servo-header-ground-isolation.md)
  for why.
- **Tight-pitch connectors and multimeter probes:** the servo headers are
  on a 2.54mm pitch. Prefer soldered or alligator-clipped test leads over
  hand-held pointed probes when checking voltages there — a probe slip
  bridging two adjacent pins destroyed a board during this build's
  diagnosis.

## 5. Flash the firmware

Follow [`docs/servo-zeroing.md`](servo-zeroing.md) section 1 for the full
Arduino IDE setup (board support, required libraries, board/port
settings) and the USB port note (use the UART port, not the native-USB
port, for flashing — on this hardware it's the port on the right side).

## 6. Bring-up and test, in this order

Go cold-to-hot, verifying each layer before powering the next, rather than
connecting everything and flipping the switch:

1. **Dry checks, no power, ESP32 not yet seated (or removed).** With a
   multimeter in resistance mode: confirm no continuity between the
   GPIO15/GPIO40 pad positions and neighboring copper (validates step 3).
   Confirm continuity from `J8`'s ground terminal to each servo `GND` pin
   reads near 0Ω (validates step 4's ground jumpers, or the permanent fix
   if your board has it) — this single check would have caught the ground
   isolation defect before any firmware was even involved.
2. **USB only, battery disconnected.** Flash the firmware, open Serial
   Monitor (115200 baud), confirm clean boot output (`Starting
   receiver...` then repeating `Waiting for transmitter connection...`),
   RGB LED white then red. This is a pure logic-side smoke test.
3. **Battery only, USB disconnected.** Check `U1` (6V) and `U2` (5V)
   output voltage — and just as importantly, check voltage **at the
   actual servo/motor connectors**, not only at the UBEC's own output
   terminal. A rail can measure perfectly clean at its source while never
   reaching the load if something's broken downstream (exactly what
   happened with the ground isolation defect). All four servos should
   snap once to center on boot and hold — that's the servo-zero check;
   see [`docs/servo-zeroing.md`](servo-zeroing.md) section 3 for details
   and what a buzzing/chattering servo means (cut power immediately).
4. **Bind the transmitter and receiver.** Follow
   [`docs/elrs-wiring.md`](elrs-wiring.md#method-2-traditional-button-bind)
   (button-bind method). If binding doesn't complete and the receiver has
   ever been flashed with a custom binding phrase before, it won't
   re-enter bind mode until that phrase is explicitly cleared first — see
   the callout in that doc.
5. **Full-range control test.** Cycle both sticks through their full range
   (individually and together) and cycle every switch through every
   permutation, watching steering, throttle, and spin-in-place respond
   correctly with no unexpected behavior at any input combination.

If something doesn't respond, check power **at the connector actually
driving the silent component** before suspecting firmware — in this
build, both major failures (a shorted motor supply, and four isolated
servo grounds) looked identical to a code problem until traced with a
multimeter.

## Common pitfalls quick-reference

| Symptom | Cause | Where it's covered |
|---|---|---|
| Board won't flash / boot-loops after a COM dropout | Corrupted flash partition or genuine hardware fault (spare-board swap is the fastest diagnostic) | [`docs/development-log.md`](development-log.md#first-power-on-and-an-esp32-hardware-fault) |
| Possible short between two specific header pin positions | Copper pour proximity — GPIO15/GPIO40 | [ADR 0001](adr/0001-esp32-header-pin-trimming.md) |
| Receiver won't enter bind mode | A binding phrase was set previously and was never cleared | [`docs/elrs-wiring.md`](elrs-wiring.md) |
| No servo/motor movement despite clean rail voltage at the UBEC | Rail measured at the source, not the load connector — check downstream | [`docs/development-log.md`](development-log.md#full-system-retest-surfaces-two-real-unrelated-defects) |
| All four servos silent, motors fine | Servo header GND pads isolated from ground pour | [ADR 0002](adr/0002-servo-header-ground-isolation.md) |
| One motor channel dead, other fine, same firmware | Check the motor driver's enable pins and the power distribution terminal block wiring before suspecting the driver itself | [`docs/development-log.md`](development-log.md#full-system-retest-surfaces-two-real-unrelated-defects) |
| Board damaged while probing with a multimeter | Bare pointed probes bridging adjacent pins on a tight-pitch header | This guide, step 4 |

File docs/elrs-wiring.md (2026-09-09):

# ELRS Receiver Wiring & Radio Setup

This document covers wiring the RadioMaster ELRS-RP3-V2 receiver to the ESP32-S3,
binding it to the BETAFPV LiteRadio 2 SE transmitter, and understanding how the
firmware maps RC channels to rover controls.

---

## Hardware Used

| Component | Model |
|---|---|
| Microcontroller | ESP32-S3 |
| RC Receiver | RadioMaster ELRS-RP3-V2 (2.4 GHz ELRS V3) |
| RC Transmitter | BETAFPV LiteRadio 2 SE (2.4 GHz ELRS V3) |
| Firmware | `pathfinder/firmware-elrs/firmware-elrs.ino` |

---

## Receiver Wiring (RP3-V2 → ESP32-S3)

The firmware communicates with the receiver over CRSF serial protocol using
HardwareSerial port 2 at 420,000 baud. The serial pins are defined in the firmware:

```cpp
#define RX_PIN 47   // ESP32 receives data FROM receiver (green wire)
#define TX_PIN 21   // ESP32 sends telemetry TO receiver (white wire)
```

Neither pin conflicts with the motor driver or servo pins already assigned.

### Wire Connections

| Wire color | Receiver label | ESP32-S3 pin |
|---|---|---|
| Red | VCC | 5V |
| Black | GND | GND |
| Green | TX (receiver output) | GPIO 47 |
| White | RX (receiver input) | GPIO 21 |

> **Note on cross-connection:** The receiver's TX (green) connects to the ESP32's
> RX pin, and the receiver's RX (white) connects to the ESP32's TX pin. This
> cross-connect is standard for any UART serial link.

> **Logic level:** The RP3-V2 outputs 3.3V logic on its signal lines even when
> powered from 5V. Connecting directly to ESP32-S3 GPIO pins is safe — no level
> shifter required.

### Already-Assigned ESP32 Pins (for reference)

| GPIO | Assignment |
|---|---|
| 7 | Servo #2 (white signal wire) |
| 10 | BTS #2 – pin 1 |
| 11 | BTS #2 – pin 2 |
| 12 | BTS #1 – pin 1 |
| 13 | BTS #1 – pin 2 |
| 21 | ELRS receiver RX (white wire) ← new |
| 38 | Servo #4 (white signal wire) |
| 41 | Servo #3 (white signal wire) |
| 42 | Servo #1 (white signal wire) |
| 47 | ELRS receiver TX (green wire) ← new |
| 48 | Onboard RGB LED (firmware-managed) |

---

## Binding the Transmitter and Receiver

Both devices run ELRS 2.4 GHz V3 and are fully compatible. Two binding methods
are available. **Neither device has a screen** — the LiteRadio 2 SE is a
gamepad-style transmitter (no OpenTX/EdgeTX menu system) and the RP3-V2 is a
bare chip-scale receiver, so both binding methods below rely on physical
buttons/power-cycling, not on-screen menus.

### Method 2: Traditional Button Bind (Recommended here)

Uses each device's factory-default identity (RP3-V2 ships with no binding
phrase set — it binds via chip ID). **No PC software required at all**, which
makes this the path to use if the BETAFPV Configurator or ExpressLRS
Configurator is giving you trouble.

> **Gotcha, confirmed on this build:** a receiver that has ever been flashed
> with a binding phrase (Method 1) **will not enter manual bind mode at
> all**, even though its LED may still change patterns in a way that looks
> like it's searching. If Method 2 isn't working and the receiver was ever
> given a custom phrase, go clear it first: reconnect to the receiver's WiFi
> config page (or ExpressLRS Configurator) and **delete the binding phrase
> field so it's genuinely blank**, then save/reflash, before retrying the
> steps below. This was the actual root cause the first time through this
> procedure on this build — the receiver had a phrase set but the
> transmitter (see Method 1's compatibility note below) never got a
> matching one, so nothing could ever pair no matter how the button-bind
> timing was adjusted.

1. Put the **RP3-V2 receiver** into bind mode: power it on, then rapidly
   power-cycle it 3 times in quick succession (unplug/replug receiver power
   three times, each off-period under ~2 seconds). Its LED should
   double-blink quickly to confirm bind mode. (It has no physical bind
   button — this power-cycle sequence is the substitute.)
2. Put the **LiteRadio 2 SE transmitter** into bind mode: power it on, then
   press the **Bind button** once — a small recessed button on the
   transmitter body **to the left of its USB charging port**, distinct from
   the 4 AUX toggle switches on the front. Its LED flashes red to confirm
   bind mode.
3. Within a few seconds the two should pair — the receiver's LED goes solid
   to confirm binding is complete.

### Method 1: Custom Binding Phrase (not usable on this build — reference only)

Lets you set a memorable private phrase instead of relying on the RP3-V2's
factory chip ID — mainly useful if other ELRS gear might be nearby and you
want to guarantee no cross-binding. More involved than it sounds: the
LiteRadio 2 SE has no menu to type a phrase into directly, so **BETAFPV
Configurator** is required to set it on the transmitter side, and the
resulting UID bytes then have to be entered manually into the receiver via
its CLI.

**Confirmed not usable on this build's transmitter unit**: this specific
LiteRadio 2 SE is missing the sticker BETAFPV uses to mark units compatible
with their Configurator software, and setting a phrase on the receiver only
(with no way to match it on the transmitter) is what caused the extended
bind failure documented in Method 2's callout above. Left here for
reference in case a compatible transmitter is used in the future — use
Method 2 for this build.

1. Download and install **BETAFPV Configurator**:
   `https://github.com/BETAFPV/BETAFPV_Configurator/releases`
2. In the Configurator, set a binding phrase for the LiteRadio 2 SE, save,
   and reboot the transmitter. Note the UID bytes the Configurator
   generates from your phrase.
3. Flash the **RP3-V2 receiver** via **ExpressLRS Configurator**
   (`https://github.com/ExpressLRS/ExpressLRS-Configurator/releases`,
   a separate tool from BETAFPV Configurator) using its WiFi method — the
   receiver hosts its own access point (`ExpressLRS RX`, password
   `expresslrs`) after ~60 seconds unbound; connect to it and browse to
   `http://10.0.0.1`. Enter the same binding phrase there, or if only UID
   bytes are supported, enter those bytes via the receiver's Betaflight CLI.
4. Power both devices on — they connect automatically.

---

## RC Channel Mapping

The firmware reads three CRSF channels and maps them to rover functions:

| CRSF Channel | Rover Function | LiteRadio 2 SE stick (Mode 2) |
|---|---|---|
| Ch 1 | Steering — left/right | Right stick, horizontal |
| Ch 3 | Throttle — forward/reverse | Left stick, vertical |
| Ch 4 | Spin in place | Right stick, vertical |

The LiteRadio 2 SE ships in Mode 2 by default, so no transmitter reconfiguration
is needed.

Spin mode activates only when Ch 4 is deflected **and** throttle and steering are
both within the deadzone (±10% of center). See
[firmware-elrs.ino lines 98-105](../pathfinder/firmware-elrs/firmware-elrs.ino#L98-L105).

---

## Required Arduino Libraries

Install both libraries in Arduino IDE before uploading the firmware:

| Library | Purpose | Install via |
|---|---|---|
| `AlfredoCRSF` | CRSF serial protocol for ELRS | Arduino Library Manager |
| `Adafruit NeoPixel` | Onboard RGB status LED | Arduino Library Manager |

**Tools → Manage Libraries → search by name → Install**

---

## LED Status Indicators

The firmware uses the onboard RGB LED (GPIO 48) to indicate link state:

| LED color | Meaning |
|---|---|
| White | Startup / initializing |
| Green | Transmitter link is active |
| Red | Waiting for transmitter signal |

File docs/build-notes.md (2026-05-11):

# Background
This project is something I cloned from an online repo shared by a public makerspace repo and described in the README.md file.  

I am building the full size (pathfinder) design.
- You may ignore the files in the 'pathfinder-mini' folder.  That is a different project I am not building.
- I don't believe we need the 'android-controller' or 'desktop-controller' folders either as I intend to use a standard R/C controller. See below section.

I have completed the 3D printing and am in the process of setting up the electronics per my custom interpretation of a wiring diagram schematic provided by the project owner.  

# My specific project goals
1. Improve the existing documentation, particularly the README.md file to better reflect the current state of my version of the project and the build process.  
2. Add documentation for the changes I have made to the electronics and software.  
3. Add documentation for any new features I add to the project.  
4. I do not want to contribute back to the online project yet, so I may need to fork (?) this to my own repo for code control for the enhancements I am making?  I'm not clear on how to fork online projects or maintain a copy for my own use.  I believe this is allowed under the Apache 2.0 license (file in the project root).

# Gap analysis
1. I intend to use the firmware-elrs section of the repository but I have never done an RC project before so I'm unclear exactly how to wire up the antenna / receiver with the ESP32 component.  
2. I have a RadioMaster ELRS-RP3-V2 receiver for the ELRS component.  I need to know how to wire this into the ESP32 as the project owner did not specify how to add this.  (red, black, green, white wire connections - where to connect each to the ESP32.)
    a. I'm not sure if you can read the 'Papaya Wiring Layout.xlsx' file but this has the wiring connections in progress.
    b. On the ESP32, the following pins have already been assigned: 
        - Pin 7: Servo #2 white
        - Pin 10: BTS #2 - pin 1
        - Pin 11: BTS #2 - pin 2
        - Pin 12: BTS #1 - pin 1
        - Pin 13: BTS #1 - pin 2
        - pin 38: Servo #4 white
        - pin 41: Servo #3 white
        - pin 42: Servo #1 white
        - 5V IN
        - Ground (by 5V IN)
        - Ground (by TX)
3. I have a BETAFPV LiteRadio 2 SE Radio Transmitter, ELRS V3 2.4 GHz model for the controller.  I need to know how to bind this to the receiver and how to configure the firmware given with the ./firmware-elrs/firmware-elrs.ino file to work with this transmitter.

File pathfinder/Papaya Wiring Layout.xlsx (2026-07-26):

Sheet: Wiring Layout v2
 |  |  |  |  |  |  |  |  |  |  |  |  |  |  |  |  | K-B | <----------- | <----------- | <----------- | <----------- | <----------- | (-) | BATTERY
 |  |  | Read from the right corner as 'column' then 'row' letter |  |  |  |  |  |  |  |  |  |  |  |  |  | K-C | <----------- | SWITCH | <----------- | FUSE | <----------- | (+)
 |  |  |  | A-A then A-B, etc moving down a column…
 |  | Z | Y | X | W | V | U | T | S | R | Q | P | O | N | M | L | K | J | I | H | G | F | E | D | C | B | A | 0/0
AE | A | "Z-A" |  |  |  | (BUS) |  |  |  | "R-A" |  |  |  | (BUS) |  |  |  | 12V SUPPLY |  | "H-A" | (BUS) |  |  |  |  |  | "A-A" | A | AE
AD | B | "Z-B" |  |  | (-) | BTS1-B- | BTS2-B- | D-B |  |  |  |  |  | G-B | (U1-) | T-N | 12V- | (-) |  |  | N-B | T-S | U1-O(-) | T-B | B-K | H-I | "A-B" | B | AD
AC | C |  |  |  | (+) | BTS1-B+ | BTS2-B+ | N-C |  |  |  |  |  | T-C | (U1+) | W-N | 12V+ | (+) |  |  | MASTER GROUND |  |  |  |  |  |  | C | AC
AB | D |  |  |  |  | (BUS) |  |  |  |  |  |  |  | (BUS) |  |  |  |  |  |  |  |  |  |  |  |  |  | D | AB
AA | E |  |  |  |  | BTS SUPPLY/RETURN |  |  |  |  |  |  |  | POWER DISTRO |  |  |  |  |  |  |  |  |  |  |  |  |  | E | AA
Z | F |  | (BUS) |  |  |  |  |  |  |  |  |  |  |  |  |  |  |  |  |  |  |  | (BUS) |  |  |  |  | F | Z
Y | G |  | BTS1-7 | Y-J | BTS1-4 | BTS1-3 |  |  |  |  | ESP32 OVERHANG |  |  |  |  |  |  |  |  |  |  |  | X-J | BTS2-7 | BTS2-4 | BTS2-3 |  | G | Y
X | H |  | MC SUPPLY 1 |  |  |  |  |  |  | (old N) |  |  |  |  |  |  |  |  |  | (old X) |  |  | MC SUPPLY 2 |  |  |  |  | H | X
W | I |  | (BUS) |  |  |  |  |  |  |  | 3V3 |  |  |  |  |  |  |  | GND | B-B |  |  |  |  |  |  |  | I | W
V | J | (+) | X-G | E-G | R-AC | W-S |  |  |  |  | 3V3 |  |  |  |  |  |  |  | TX |  |  | (BUS) |  |  |  |  |  | J | V
U | K | (-) | BTS1-8 | BTS2-8 | R-AD | 5V/3A SUPPLY |  |  |  |  | RST |  |  |  |  |  |  |  | BX |  |  | Y-P | Y-AA | B-P | B-AA | C-B | (-) | K | U
T | L |  | (BUS) |  |  |  |  |  |  |  | 4 |  |  |  |  |  |  |  | 1 |  |  | Y-Q | Y-AB | B-Q | B-AB | U1-O+ | (+) | L | T
S | M |  |  |  |  |  |  |  |  |  | 5 |  |  |  |  |  |  |  | 2 |  |  | (BUS) |  |  |  |  |  | M | S
R | N |  |  |  | L-C | IN+ | IN- | L-B |  |  | 6 |  |  |  |  |  |  | (S1) | 42 | Y-AC | WHITE | SERVO SUPPLY / RETURN |  |  |  |  |  | N | R
Q | O |  |  |  |  | UBEC 5V (small) U2 |  |  | WHITE | B-AC | 7 | (S2) |  |  |  |  |  | (S3) | 41 | Y-R | WHITE |  |  |  |  |  |  | O | Q
P | P | blk | F-K |  |  |  |  |  |  |  | 15 |  |  |  |  |  |  |  | 40 |  |  |  |  |  | blk | D-K |  | P | P
O | Q | red | F-L |  |  |  |  |  |  |  | 16 |  |  |  |  |  |  |  | 39 |  |  |  |  |  | red | D-L |  | Q | O
N | R | wht | H-O |  |  |  |  |  |  |  | 17 |  |  |  | ESP32 |  |  | (S4) | 38 | B-R | WHITE |  |  |  | wht | H-R |  | R | N
M | S |  | S3 |  | V-J | V0+ | V0- | W-B |  |  | 18 |  |  |  |  |  |  |  | 37 |  |  |  |  |  |  | S4 |  | S | M
L | T |  | (+) | (-) |  |  |  |  |  |  | 8 |  |  |  |  |  |  |  | 36 |  |  |  |  |  | (-) | (+) |  | T | L
K | U | (BUS) | BTS1-M+ | BTS1-M(-) | (BUS) |  |  |  |  |  | 3 |  |  |  |  |  |  |  | 35 |  |  |  |  | (BUS) | BTS2-M(-) | BTS2-M+ | (BUS) | U | K
J | V |  | M5+ | M5- |  |  |  |  |  |  | 46 |  |  |  |  |  |  |  | 0 |  |  |  |  |  | M6- | M6+ |  | V | J
I | W |  | M3+ | M3- |  |  |  |  |  |  | 9 |  |  |  |  |  |  |  | 45 |  |  |  |  |  | M4- | M4+ |  | W | I
H | X |  | M1+ | M1- |  |  |  |  | GRAY | BTS2-1 | 10 |  |  |  |  |  |  |  | 48 |  |  |  |  |  | M2- | M2+ |  | X | H
G | Y |  | MSB1 |  |  |  |  |  | GREEN | BTS2-2 | 11 |  |  |  |  |  |  |  | 47 |  |  |  |  |  | MSB2 |  |  | Y | G
F | Z |  |  |  |  |  |  |  | GREEN | BTS1-1 | 12 |  |  |  |  |  |  |  | 21 |  |  |  |  |  |  |  |  | Z | F
E | AA | blk | E-K |  |  |  |  |  | GRAY | BTS1-2 | 13 |  |  |  |  |  |  |  | 20 |  |  |  |  |  | blk | C-K |  | AA | E
D | AB | red | E-L |  |  |  |  |  |  |  | 14 |  |  |  |  |  |  |  | 19 |  |  |  |  |  | red | C-L |  | AB | D
C | AC | wht | H-N |  |  |  |  |  |  | W-J | 5V IN |  |  |  |  |  |  |  | GND |  |  |  |  |  | wht | R-O |  | AC | C
B | AD |  | S1 |  |  |  |  |  |  | W-K | GND |  |  |  |  |  |  |  | GND |  |  |  |  |  |  | S2 |  | AD | B
A | AE | "Z-AE" |  |  |  |  |  |  |  | "R-AE" |  |  |  |  |  |  |  |  |  | "H-AE" |  |  |  |  |  |  | "A-AE" | AE | A
 |  | Z | Y | X | W | V | U | T | S | R | Q | P | O | N | M | L | K | J | I | H | G | F | E | D | C | B | A
 |  | V-B | V-C | X-U | Y-U |  |  |  |  | INPUT | M-B | M-C |  |  |  |  |  |  |  |  |  |  | U-B | U-C | C-U | B-U
 |  | B- | B+ | M- | M+ |  |  |  |  |  | (-) | (+) |  |  |  |  |  |  |  |  |  |  | B- | B+ | M- | M+
 |  | VCC | R-IS | R-EN | R-PWM |  |  |  |  |  |  |  |  |  |  |  |  |  |  |  |  |  | VCC | R-IS | R-EN | R-PWM
 | 7 | Y-G | (3->) | V-G | R-Z | 1 |  |  |  |  |  |  |  |  |  |  |  |  |  |  |  | 7 | D-G | (3->) | B-G | R-X | 1
 | 8 | Y-K | (4->) | W-G | R-AA | 2 |  |  |  | OUTPUT | E-B | B-L |  |  |  |  |  |  |  |  |  | 8 | X-K | (4->) | C-G | R-Y | 2
 |  | GND | L-IS | L-EN | L-PWM |  |  |  |  |  | (-) | (+) |  |  |  |  |  |  |  |  |  |  | GND | L-IS | L-EN | L-PWM
 | BTS 1 -- OFF BOARD |  |  |  |  |  |  |  |  | UBEC (U1) 6V/8A -- OFF BOARD |  |  |  |  |  |  |  |  |  |  |  | BTS 2 -- OFF BOARD
 |  |  |  |  |  |  |  |  |  | Y-AA / Y-AB / Y-AC |  |  | Y-P / Y-Q / Y-R |  |  | B-AA / B-AB / B-AC |  |  | B-P / B-Q / B-R
 | (+) | (-) |  | (+) | (-) |  | (+) | (-) |  | BLK-RED-WHT |  |  | BLK-RED-WHT |  |  | BLK-RED-WHT |  |  | BLK-RED-WHT |  |  | (+) | (-) |  | (+) | (-) |  | (+) | (-)
 | Y-X | X-X |  | Y-W | X-W |  | Y-V | X-V |  | (PREWIRED) |  |  | (PREWIRED) |  |  | (PREWIRED) |  |  | (PREWIRED) |  |  | B-X | C-X |  | B-W | C-W |  | B-V | C-V
 | MOTOR 1 |  |  | MOTOR 3 |  |  | MOTOR 5 |  |  | SERVO S1 |  |  | SERVO S3 |  |  | SERVO S2 |  |  | SERVO S4 |  |  | MOTOR 2 |  |  | MOTOR 4 |  |  | MOTOR 6

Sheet: Wiring Layout
 |  |  |  |  |  |  |  |  |  |  |  |  |  |  |  |  | K-B | <----------- | <----------- | <----------- | <----------- | <----------- | (-) | BATTERY
 |  |  | Read from the right corner as 'column' then 'row' letter |  |  |  |  |  |  |  |  |  |  |  |  |  | K-C | <----------- | SWITCH | <----------- | FUSE | <----------- | (+)
 |  |  |  | A-A then A-B, etc moving down a column…
 |  | Z | Y | X | W | V | U | T | S | R | Q | P | O | N | M | L | K | J | I | H | G | F | E | D | C | B | A | 0/0
AE | A | "Z-A" |  |  |  | (BUS) |  |  |  | "R-A" |  |  |  | (BUS) |  |  |  | 12V SUPPLY |  | "H-A" | (BUS) |  |  |  |  |  | "A-A" | A | AE
AD | B | "Z-B" |  |  | (-) | BTS1-B- | BTS2-B- | D-B |  |  |  |  |  | G-B | (U1-) | T-N | 12V- | (-) |  |  | N-B | T-S | U1-O(-) | T-B | B-K | H-I | "A-B" | B | AD
AC | C |  |  |  | (+) | BTS1-B+ | BTS2-B+ | N-C |  |  |  |  |  | T-C | (U1+) | W-N | 12V+ | (+) |  |  | MASTER GROUND |  |  |  |  |  |  | C | AC
AB | D |  |  |  |  | (BUS) |  |  |  |  |  |  |  | (BUS) |  |  |  |  |  |  |  |  |  |  |  |  |  | D | AB
AA | E |  |  |  |  | BTS SUPPLY/RETURN |  |  |  |  |  |  |  | POWER DISTRO |  |  |  |  |  |  |  |  |  |  |  |  |  | E | AA
Z | F |  | (BUS) |  |  |  |  |  |  |  |  |  |  |  |  |  |  |  |  |  |  |  | (BUS) |  |  |  |  | F | Z
Y | G |  | BTS1-7 | Y-J | BTS1-4 | BTS1-3 |  |  |  |  | ESP32 OVERHANG |  |  |  |  |  |  |  |  |  |  |  | X-J | BTS2-7 | BTS2-4 | BTS2-3 |  | G | Y
X | H |  | MC SUPPLY 1 |  |  |  |  |  |  | (old N) |  |  |  |  |  |  |  |  |  | (old X) |  |  | MC SUPPLY 2 |  |  |  |  | H | X
W | I |  | (BUS) |  |  |  |  |  |  |  | 3V3 |  |  |  |  |  |  |  | GND | B-B |  |  |  |  |  |  |  | I | W
V | J | (+) | X-G | E-G | R-AC | W-S |  |  |  |  | 3V3 |  |  |  |  |  |  |  | TX |  |  | (BUS) |  |  |  |  |  | J | V
U | K | (-) | BTS1-8 | BTS2-8 | R-AD | 5V/3A SUPPLY |  |  |  |  | RST |  |  |  |  |  |  |  | BX |  |  | Y-P | Y-AA | B-P | B-AA | C-B | (-) | K | U
T | L |  | (BUS) |  |  |  |  |  |  |  | 4 |  |  |  |  |  |  |  | 1 |  |  | Y-Q | Y-AB | B-Q | B-AB | U1-O+ | (+) | L | T
S | M |  |  |  |  |  |  |  |  |  | 5 |  |  |  |  |  |  |  | 2 |  |  | (BUS) |  |  |  |  |  | M | S
R | N |  |  |  | L-C | IN+ | IN- | L-B |  |  | 6 |  |  |  |  |  |  | (S1) | 42 | Y-AC | WHITE | SERVO SUPPLY / RETURN |  |  |  |  |  | N | R
Q | O |  |  |  |  | UBEC 5V (small) U2 |  |  | WHITE | B-AC | 7 | (S2) |  |  |  |  |  | (S3) | 41 | Y-R | WHITE |  |  |  |  |  |  | O | Q
P | P | blk | F-K |  |  |  |  |  |  |  | 15 |  |  |  |  |  |  |  | 40 |  |  |  |  |  | blk | D-K |  | P | P
O | Q | red | F-L |  |  |  |  |  |  |  | 16 |  |  |  |  |  |  |  | 39 |  |  |  |  |  | red | D-L |  | Q | O
N | R | wht | H-O |  |  |  |  |  |  |  | 17 |  |  |  | ESP32 |  |  | (S4) | 38 | B-R | WHITE |  |  |  | wht | H-R |  | R | N
M | S |  | S3 |  | V-J | V0+ | V0- | W-B |  |  | 18 |  |  |  |  |  |  |  | 37 |  |  |  |  |  |  | S4 |  | S | M
L | T |  | (+) | (-) |  |  |  |  |  |  | 8 |  |  |  |  |  |  |  | 36 |  |  |  |  |  | (-) | (+) |  | T | L
K | U | (BUS) | BTS1-M+ | BTS1-M(-) | (BUS) |  |  |  |  |  | 3 |  |  |  |  |  |  |  | 35 |  |  |  |  | (BUS) | BTS2-M(-) | BTS2-M+ | (BUS) | U | K
J | V |  | M5+ | M5- |  |  |  |  |  |  | 46 |  |  |  |  |  |  |  | 0 |  |  |  |  |  | M6- | M6+ |  | V | J
I | W |  | M3+ | M3- |  |  |  |  |  |  | 9 |  |  |  |  |  |  |  | 45 |  |  |  |  |  | M4- | M4+ |  | W | I
H | X |  | M1+ | M1- |  |  |  |  | GRAY | BTS2-1 | 10 |  |  |  |  |  |  |  | 48 |  |  |  |  |  | M2- | M2+ |  | X | H
G | Y |  | MSB1 |  |  |  |  |  | GREEN | BTS2-2 | 11 |  |  |  |  |  |  |  | 47 |  |  |  |  |  | MSB2 |  |  | Y | G
F | Z |  |  |  |  |  |  |  | GREEN | BTS1-1 | 12 |  |  |  |  |  |  |  | 21 |  |  |  |  |  |  |  |  | Z | F
E | AA | blk | E-K |  |  |  |  |  | GRAY | BTS1-2 | 13 |  |  |  |  |  |  |  | 20 |  |  |  |  |  | blk | C-K |  | AA | E
D | AB | red | E-L |  |  |  |  |  |  |  | 14 |  |  |  |  |  |  |  | 19 |  |  |  |  |  | red | C-L |  | AB | D
C | AC | wht | H-N |  |  |  |  |  |  | W-J | 5V IN |  |  |  |  |  |  |  | GND |  |  |  |  |  | wht | R-O |  | AC | C
B | AD |  | S1 |  |  |  |  |  |  | W-K | GND |  |  |  |  |  |  |  | GND |  |  |  |  |  |  | S2 |  | AD | B
A | AE | "Z-AE" |  |  |  |  |  |  |  | "R-AE" |  |  |  |  |  |  |  |  |  | "H-AE" |  |  |  |  |  |  | "A-AE" | AE | A
 |  | Z | Y | X | W | V | U | T | S | R | Q | P | O | N | M | L | K | J | I | H | G | F | E | D | C | B | A
 |  | V-B | V-C | X-U | Y-U |  |  |  |  | INPUT | M-B | M-C |  |  |  |  |  |  |  |  |  |  | U-B | U-C | C-U | B-U
 |  | B- | B+ | M- | M+ |  |  |  |  |  | (-) | (+) |  |  |  |  |  |  |  |  |  |  | B- | B+ | M- | M+
 |  | VCC | R-IS | R-EN | R-PWM |  |  |  |  |  |  |  |  |  |  |  |  |  |  |  |  |  | VCC | R-IS | R-EN | R-PWM
 | 7 | Y-G | (3->) | V-G | R-Z | 1 |  |  |  |  |  |  |  |  |  |  |  |  |  |  |  | 7 | D-G | (3->) | B-G | R-X | 1
 | 8 | Y-K | (4->) | W-G | R-AA | 2 |  |  |  | OUTPUT | E-B | B-L |  |  |  |  |  |  |  |  |  | 8 | X-K | (4->) | C-G | R-Y | 2
 |  | GND | L-IS | L-EN | L-PWM |  |  |  |  |  | (-) | (+) |  |  |  |  |  |  |  |  |  |  | GND | L-IS | L-EN | L-PWM
 | BTS 1 -- OFF BOARD |  |  |  |  |  |  |  |  | UBEC (U1) 6V/8A -- OFF BOARD |  |  |  |  |  |  |  |  |  |  |  | BTS 2 -- OFF BOARD
 |  |  |  |  |  |  |  |  |  | Y-AA / Y-AB / Y-AC |  |  | Y-P / Y-Q / Y-R |  |  | B-AA / B-AB / B-AC |  |  | B-P / B-Q / B-R
 | (+) | (-) |  | (+) | (-) |  | (+) | (-) |  | BLK-RED-WHT |  |  | BLK-RED-WHT |  |  | BLK-RED-WHT |  |  | BLK-RED-WHT |  |  | (+) | (-) |  | (+) | (-) |  | (+) | (-)
 | Y-X | X-X |  | Y-W | X-W |  | Y-V | X-V |  | (PREWIRED) |  |  | (PREWIRED) |  |  | (PREWIRED) |  |  | (PREWIRED) |  |  | B-X | C-X |  | B-W | C-W |  | B-V | C-V
 | MOTOR 1 |  |  | MOTOR 3 |  |  | MOTOR 5 |  |  | SERVO S1 |  |  | SERVO S3 |  |  | SERVO S2 |  |  | SERVO S4 |  |  | MOTOR 2 |  |  | MOTOR 4 |  |  | MOTOR 6

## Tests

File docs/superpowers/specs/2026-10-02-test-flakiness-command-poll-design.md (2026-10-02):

# Full-Suite Test Flakiness: Missing `/commands/poll` Handler Coverage — Design

**Status:** Approved, pending plan
**Related:** `docs/phase2/inputs/00-inbox.md` (observation logged across several plans this session)

## Root cause

`COMMAND_POLL_INTERVAL_S = 1.0` (`runtime_config.py:18`) — a genuinely short interval. `MissionRuntime.startup()` arms `_last_command_poll_monotonic = time.monotonic()`; any later `tick()` call whose real wall-clock gap since `startup()` exceeds 1.0 second makes `_poll_and_handle_commands_if_due` call `backend_client.poll_commands`, which issues `GET {base_url}/commands/poll/{rover_id}` (`backend_client.py:31`).

Six test files construct a `MissionRuntime` against a fake HTTP handler (via `httpx.MockTransport`) that does **not** implement that path, and falls through to `raise AssertionError(request.url.path)` for anything unhandled:

- `tests/test_digital_twin_scenarios.py`
- `tests/test_hardware_drivers_integration.py`
- `tests/test_runtime_resume.py`
- `tests/test_runtime_startup.py`
- `tests/test_runtime_tick_sensing.py`
- `tests/test_status_display_integration.py`

In isolation, a single test runs in milliseconds — nowhere near the 1-second threshold — so it never fires. Under a full ~270-test suite run, system load (CPU contention, disk I/O across many `tmp_path`-backed SQLite files running back-to-back) can occasionally stretch one specific test's own wall-clock execution between its `startup()` call and a later `tick()` call past 1 second, even though that same test is fast in isolation. When that happens, the legitimate, production-correct command-poll fires, hits one of these six handlers, and crashes the test with an `AssertionError` on `/commands/poll/rover-1` — which looks like "flaky," unrelated test failure, but is really just an incomplete test fixture meeting code it was never written to anticipate.

Two other files that ARE about command polling already handle this path correctly and were never affected: `tests/test_runtime_sync_and_integration.py` and `tests/test_runtime_tick_commands.py`.

**Clarification (added after final review):** of the six files above, only four were ever actually reachable by this bug via existing code paths at the time of this fix — `test_digital_twin_scenarios.py`, `test_hardware_drivers_integration.py`, `test_runtime_tick_sensing.py`, and `test_status_display_integration.py`, all of which had existing tests calling `tick()` after `startup()`. `test_runtime_startup.py` and `test_runtime_resume.py`'s existing fixture helpers never called `tick()` at all in their pre-fix form (only `startup()`/`handle_start_sweep()`), so those two were never actually observed failing — they were fixed defensively/future-proofed, since they construct a `MissionRuntime` against the same kind of fixture and could plausibly grow a `tick()` call later.

## Fix

Add one branch to each of the six affected `_handler`/`_handler_for` functions, matching the exact pattern already used in `test_runtime_tick_commands.py`:

```python
if request.url.path == "/commands/poll/rover-1":
    return httpx.Response(200, json=[])
```

None of these six tests care about command-polling behavior — they just need the poll to not crash when it fires. An empty command list is exactly what a real backend returns when there's nothing queued, so this isn't a special-case hack for tests; it's the fixture finally behaving like a real backend would under the same request.

**Five of the six files** (`test_digital_twin_scenarios.py`, `test_hardware_drivers_integration.py`, `test_runtime_resume.py`, `test_runtime_tick_sensing.py`, `test_status_display_integration.py`) share an identical or near-identical `_handler(rover, geofences)` shape — insert the new branch right before each file's `raise AssertionError(request.url.path)` line.

**`test_runtime_startup.py`** has a slightly different shape: the function is named `_handler_for` (not `_handler`), its geofence-path check is `request.url.path == "/geofences/fence-1"` (hardcoded, not a `.startswith()` prefix match), and its fallback raises `AssertionError(f"unexpected request: {request.url.path}")` (a formatted message, not the bare path). Same fix, same insertion point (right before that file's own fallback raise), adapted to its exact existing style.

## Not changing

- `COMMAND_POLL_INTERVAL_S` itself, or any other `runtime_config.py` value — this is a test-fixture fix, not a production timing change.
- `tests/test_runtime_sync_and_integration.py` and `tests/test_runtime_tick_commands.py` — already correct.
- Any production code in `papaya_mission/`.

## Testing

This fix has no new test *cases* — it makes six existing test fixtures correctly handle a request path the production code was already allowed to make. Verification is: run the full suite multiple times in a row and confirm it stays green across all runs, not just once (a single green run doesn't prove flakiness is gone — the bug is probabilistic). Each of the six touched files' own test suite should also be run individually to confirm no behavioral change for the normal (non-polling) path.

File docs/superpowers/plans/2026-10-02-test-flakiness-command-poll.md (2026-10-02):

# Full-Suite Test Flakiness: Missing `/commands/poll` Handler Coverage Implementation Plan

> **For agentic workers:** REQUIRED SUB-SKILL: Use superpowers:subagent-driven-development (recommended) or superpowers:executing-plans to implement this plan task-by-task. Steps use checkbox (`- [ ]`) syntax for tracking.

**Goal:** Eliminate a real, confirmed source of full-suite test flakiness: six test files' fake HTTP handlers crash with `AssertionError` when `MissionRuntime`'s legitimate 1-second command-poll fires mid-test (which it occasionally does under full-suite system load, even though the same test is fast in isolation), because those handlers never implemented `/commands/poll/{rover_id}`.

**Architecture:** Add one branch to each of the six affected handler functions, returning an empty command list — matching the exact pattern already used (correctly) in `tests/test_runtime_tick_commands.py`. Pure test-fixture fix; no production code changes.

**Tech Stack:** Python 3.12, pytest, httpx. No new dependencies.

## Global Constraints

- No change to `COMMAND_POLL_INTERVAL_S` or any other value in `papaya_mission/runtime_config.py` — this is a test-fixture fix, not a production timing change.
- No change to any file in `papaya_mission/` (production code) at all.
- No change to `tests/test_runtime_sync_and_integration.py` or `tests/test_runtime_tick_commands.py` — both already handle `/commands/poll/rover-1` correctly.
- Every rover id across all six affected tests is `"rover-1"` (verified) — the new branch always checks `/commands/poll/rover-1` and always returns `httpx.Response(200, json=[])`, an empty command list.
- Design spec: `docs/superpowers/specs/2026-10-02-test-flakiness-command-poll-design.md`.

---

## File Structure

```
pathfinder-autonomous/pi-mission/tests/
  test_digital_twin_scenarios.py        # MODIFY -- _handler, one new branch
  test_hardware_drivers_integration.py  # MODIFY -- _handler, one new branch
  test_runtime_resume.py                # MODIFY -- _handler, one new branch
  test_runtime_startup.py               # MODIFY -- _handler_for, one new branch
  test_runtime_tick_sensing.py          # MODIFY -- _handler, one new branch
  test_status_display_integration.py    # MODIFY -- _handler, one new branch
```

---

### Task 1: Add `/commands/poll/rover-1` handling to the six affected test fixtures

**Files:**
- Modify: `pathfinder-autonomous/pi-mission/tests/test_digital_twin_scenarios.py`
- Modify: `pathfinder-autonomous/pi-mission/tests/test_hardware_drivers_integration.py`
- Modify: `pathfinder-autonomous/pi-mission/tests/test_runtime_resume.py`
- Modify: `pathfinder-autonomous/pi-mission/tests/test_runtime_startup.py`
- Modify: `pathfinder-autonomous/pi-mission/tests/test_runtime_tick_sensing.py`
- Modify: `pathfinder-autonomous/pi-mission/tests/test_status_display_integration.py`

**Interfaces:**
- Consumes: `httpx.Response`, `httpx.Request` (unchanged, already imported in every one of these files).
- Produces: nothing consumed by a later task — this plan has one task.

This task has no new test to write first (there is no reproducible failing test for a probabilistic timing bug — see the spec's Testing section). Instead, each step below is a verified, exact edit; run the full suite multiple times afterward to confirm no regression and reduced flake surface.

- [ ] **Step 1: Edit `test_digital_twin_scenarios.py`**

Find this exact existing block:

```python
        if request.url.path.startswith("/geofences/"):
            fid = request.url.path.rsplit("/", 1)[-1]
            return httpx.Response(200, json=next(g for g in geofences if g["_id"] == fid))
        raise AssertionError(request.url.path)
```

Replace with:

```python
        if request.url.path.startswith("/geofences/"):
            fid = request.url.path.rsplit("/", 1)[-1]
            return httpx.Response(200, json=next(g for g in geofences if g["_id"] == fid))
        if request.url.path == "/commands/poll/rover-1":
            # This test doesn't exercise command polling -- it just needs the
            # poll to not crash if MissionRuntime's 1-second cadence
            # (COMMAND_POLL_INTERVAL_S) happens to fire mid-test under
            # full-suite system load, even though this test is fast in
            # isolation. An empty list is exactly what a real backend
            # returns when nothing is queued.
            return httpx.Response(200, json=[])
        raise AssertionError(request.url.path)
```

- [ ] **Step 2: Edit `test_hardware_drivers_integration.py`**

Find this exact existing block:

```python
        if request.url.path.startswith("/geofences/"):
            fid = request.url.path.rsplit("/", 1)[-1]
            return httpx.Response(200, json=next(g for g in geofences if g["_id"] == fid))
        raise AssertionError(request.url.path)
```

Replace with the same pattern as Step 1:

```python
        if request.url.path.startswith("/geofences/"):
            fid = request.url.path.rsplit("/", 1)[-1]
            return httpx.Response(200, json=next(g for g in geofences if g["_id"] == fid))
        if request.url.path == "/commands/poll/rover-1":
            # See test_digital_twin_scenarios.py's _handler for the full
            # rationale -- same fix, same reason.
            return httpx.Response(200, json=[])
        raise AssertionError(request.url.path)
```

- [ ] **Step 3: Edit `test_runtime_resume.py`**

Find this exact existing block:

```python
        if request.url.path.startswith("/geofences/"):
            fid = request.url.path.rsplit("/", 1)[-1]
            match = next(g for g in geofences if g["_id"] == fid)
            return httpx.Response(200, json=match)
        raise AssertionError(request.url.path)
```

Replace with:

```python
        if request.url.path.startswith("/geofences/"):
            fid = request.url.path.rsplit("/", 1)[-1]
            match = next(g for g in geofences if g["_id"] == fid)
            return httpx.Response(200, json=match)
        if request.url.path == "/commands/poll/rover-1":
            # See test_digital_twin_scenarios.py's _handler for the full
            # rationale -- same fix, same reason.
            return httpx.Response(200, json=[])
        raise AssertionError(request.url.path)
```

- [ ] **Step 4: Edit `test_runtime_startup.py`**

This file's handler is named `_handler_for` (not `_handler`) and has a different shape — a hardcoded `/geofences/fence-1` check, not a `.startswith("/geofences/")` prefix match, and its fallback message is formatted differently. Find this exact existing block:

```python
        if request.url.path == "/geofences/fence-1":
            return httpx.Response(200, json=geofences[0])
        if request.url.path == "/geofences":
            return httpx.Response(200, json=geofences)
        raise AssertionError(f"unexpected request: {request.url.path}")
```

Replace with:

```python
        if request.url.path == "/geofences/fence-1":
            return httpx.Response(200, json=geofences[0])
        if request.url.path == "/geofences":
            return httpx.Response(200, json=geofences)
        if request.url.path == "/commands/poll/rover-1":
            # See test_digital_twin_scenarios.py's _handler for the full
            # rationale -- same fix, same reason.
            return httpx.Response(200, json=[])
        raise AssertionError(f"unexpected request: {request.url.path}")
```

- [ ] **Step 5: Edit `test_runtime_tick_sensing.py`**

Find this exact existing block:

```python
        if request.url.path.startswith("/geofences/"):
            fid = request.url.path.rsplit("/", 1)[-1]
            return httpx.Response(200, json=next(g for g in geofences if g["_id"] == fid))
        raise AssertionError(request.url.path)
```

Replace with the same pattern as Step 1:

```python
        if request.url.path.startswith("/geofences/"):
            fid = request.url.path.rsplit("/", 1)[-1]
            return httpx.Response(200, json=next(g for g in geofences if g["_id"] == fid))
        if request.url.path == "/commands/poll/rover-1":
            # See test_digital_twin_scenarios.py's _handler for the full
            # rationale -- same fix, same reason.
            return httpx.Response(200, json=[])
        raise AssertionError(request.url.path)
```

- [ ] **Step 6: Edit `test_status_display_integration.py`**

Find this exact existing block:

```python
        if request.url.path.startswith("/geofences/"):
            fid = request.url.path.rsplit("/", 1)[-1]
            return httpx.Response(200, json=next(g for g in geofences if g["_id"] == fid))
        raise AssertionError(request.url.path)
```

Replace with the same pattern as Step 1:

```python
        if request.url.path.startswith("/geofences/"):
            fid = request.url.path.rsplit("/", 1)[-1]
            return httpx.Response(200, json=next(g for g in geofences if g["_id"] == fid))
        if request.url.path == "/commands/poll/rover-1":
            # See test_digital_twin_scenarios.py's _handler for the full
            # rationale -- same fix, same reason.
            return httpx.Response(200, json=[])
        raise AssertionError(request.url.path)
```

- [ ] **Step 7: Run each touched file's own test suite and verify it still passes**

Run (from `pathfinder-autonomous/pi-mission/`):

```bash
pytest tests/test_digital_twin_scenarios.py tests/test_hardware_drivers_integration.py tests/test_runtime_resume.py tests/test_runtime_startup.py tests/test_runtime_tick_sensing.py tests/test_status_display_integration.py -v
```

Expected: PASS — every existing test in all six files still passes unchanged. This step proves the new branch didn't alter any existing behavior (no test in these files currently exercises `/commands/poll/rover-1`, so none of their assertions should change).

- [ ] **Step 8: Run the full suite multiple times to confirm reduced flakiness**

Run (from `pathfinder-autonomous/pi-mission/`):

```bash
pytest -q
pytest -q
pytest -q
```

Expected: PASS all three times, back-to-back. A single green run does not prove the flakiness is fixed (the bug is probabilistic, tied to system load during that specific run) — running it 3 times in a row is the actual verification this fix is meant to satisfy. If any of the three runs fails with an error unrelated to `/commands/poll` (a different assertion, a different file), treat that as a separate, newly-discovered issue — do not attribute it to this fix.

- [ ] **Step 9: Commit**

```bash
git add pathfinder-autonomous/pi-mission/tests/test_digital_twin_scenarios.py pathfinder-autonomous/pi-mission/tests/test_hardware_drivers_integration.py pathfinder-autonomous/pi-mission/tests/test_runtime_resume.py pathfinder-autonomous/pi-mission/tests/test_runtime_startup.py pathfinder-autonomous/pi-mission/tests/test_runtime_tick_sensing.py pathfinder-autonomous/pi-mission/tests/test_status_display_integration.py
git commit -m "test(pi-mission): handle /commands/poll/rover-1 in 6 fixtures to fix full-suite flakiness"
```

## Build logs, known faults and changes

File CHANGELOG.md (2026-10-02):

# Changelog

All notable changes to this project are documented here. Versioning follows
[Semantic Versioning](https://semver.org/) (`MAJOR.MINOR.PATCH`):

- **MAJOR** — breaking/foundational changes (e.g. a new build phase, a
  hardware revision that invalidates prior wiring). Always consulted on
  before bumping.
- **MINOR** — new features or documentation additions that don't break
  what's already built (e.g. new firmware capability, new subsystem).
- **PATCH** — fixes, tuning, and small additions (e.g. trim values, BOM
  entries, doc updates).

## [2.2.3] - 2026-10-02

### Added
- `docs/adr/0004-wheeled-vs-tracked-drivetrain.md` — architecture decision
  record for keeping the wheeled rocker-bogie drivetrain over tracked/
  caterpillar, mecanum/omni, fully-independent-suspension, and legged
  alternatives, all considered and rejected in favor of retrofitting
  suspension at the one joint that's actually failing.
- `docs/phase2/inputs/04-physical-platform.md` / `05-assumptions-
  decisions.md`: first-pass mechanical/physical architecture
  brainstorm for the Phase 2 rebuild — payload bay enclosure-vs-
  footprint conflict and scale (PLT-5), a corrected diagnosis of the
  recurring wheel-strut failure as a 3D-printed steering-pivot pin
  carrying structural/impact load it was never sized for rather than
  an electrical connector (PLT-7), relocating the top-mounted
  transverse pivot link underneath the chassis (PLT-8), center-of-
  gravity weight budgeting for the larger bay (PLT-9, D-7), 6-vs-8-wheel
  drivetrain and steered-wheel-position decisions (Q-9, D-8), the
  second rear transverse link and chassis-torsion questions a dual-
  differential layout raises (Q-10, Q-11), the farm-terrain/walking-
  pace operating envelope (A-2), and drive-motor weatherproofing
  options. All open items are logged as open (TBD/leaning), not
  decided — follow-on discussion continues in a future session.

## [2.2.2] - 2026-10-02

### Added
- `MissionRuntime` gained an `ota_update` command handler: refuses to
  trigger an ESP32 firmware flash while a sweep session is actively in
  progress (checking session *status*, not mere presence — a session is
  never reset to `None` after a mission ends, so a presence-only check
  would have blocked OTA forever after the rover's first mission).

### Fixed
- A refused OTA command was believed to retry automatically via backend
  redelivery; the final review found this is false — the backend never
  moves a `"delivered"` command back to `"pending"`, so it was actually
  dropped permanently. The refusal itself was always correct and safe;
  only the retry claim was wrong. Corrected the code comments and docs,
  and added an explicit log line so a deliberate refusal is now
  distinguishable from a genuine fault. The backend-wide redelivery gap
  (affecting every command type, not just OTA) is logged as a follow-up,
  not fixed in this release.

## [2.2.1] - 2026-10-02

### Fixed
- `PositionFusion`'s fused heading only updated on ticks where no GPS fix
  arrived — on a GPS-healthy rover (the normal case), heading never
  advanced past its seed value, silently misplacing every obstacle the
  mission logs (bearing is projected from this heading). Found during the
  digital-twin simulator's final review (2026-09-26), fixed now: heading
  updates unconditionally every tick via a new, guard-free
  `PositionFusion.on_imu_heading()`, independent of GPS-fix dead-reckoning.
  The related seed-time gap (the first position estimate defaulted to
  heading `0.0` instead of the real IMU reading) is fixed too.

## [2.2.0] - 2026-10-02

### Added
- **Pi Mission Runtime (MP-1)**: the full `pathfinder-autonomous/pi-mission`
  Python client. A local SQLite store; `SensorHub`/`Esp32Link` interfaces
  with simulated/fake implementations for hardware-free testing; a backend
  read/poll client; and `MissionRuntime` itself — startup and resume-after-
  restart handling, `start_sweep`, a tick loop covering position fusion,
  obstacle detection, exclusion-zone and GPS-loss safety checks, command
  dispatch, telemetry cadence, Home-return sync, and a CLI entrypoint.
- **Digital-twin simulator** (`digital_twin.py`): a coherent simulated
  rover world (position/heading/speed, an autonomous bounded mast sweep,
  bounded GPS jitter, bump/halt detection) that derives consistent sensor
  readings from one shared state, so development and testing can continue
  end-to-end without physical hardware.
- **Breadboard bench rig hardware drivers**: `hardware_esp32_link.py` (a
  real `Esp32Link` over an injected UART transport), `hardware_sensor_hub.py`
  (GPS NMEA parsing, IMU, ultrasonic, and camera sources), and
  `status_display.py` (an LCD status display with screen cycling and
  soft-key dispatch) — every hardware dependency is injected against a
  `Protocol`, so none of this requires real hardware libraries to test.
- `MissionRuntime.last_telemetry_readings`, a live per-session obstacle
  counter, and ESP32 halted-on-contact status, wired into the LCD status
  display so it renders real runtime state end-to-end (deliberately kept
  out of the synced telemetry record for now — syncing it to ground
  control is a good longer-term idea, not built yet).

### Fixed
- The LCD drive screen couldn't distinguish "confirmed not halted" /
  "confirmed zero throttle" from "the status or drive-status read just
  failed" — both rendered identically.
- Resuming an interrupted sweep session after a process restart didn't
  seed the obstacle counter from obstacles already persisted for that
  session, and a confirmed re-detection during resume validation was
  double-counted against it.
- The LCD position screen's coordinate format silently overflowed the
  16-character display width and truncated longitude.
- A confirmed source of full-suite `pi-mission` test flakiness: two of
  `MissionRuntime`'s interval-gated timers (command-poll, telemetry-sample)
  could legitimately fire mid-test under system load, hitting test
  fixtures that hadn't been written to expect them.

## [2.1.0] - 2026-09-26

### Added
- MP-1 Backend Obstacle & Telemetry Sync: `POST /sync/sweep-sessions`,
  `/sync/obstacles`, `/sync/telemetry` — client-generated-ID upsert/insert
  sync for the Pi's sweep sessions, obstacles, and telemetry, plus a
  read-only `list_pending_review` for the Management UI plan to build on.
  Telemetry lands in a native MongoDB time-series collection.
- `docs/adr/0003-telemetry-sync-idempotency.md` — records the discovery
  that MongoDB rejects unique indexes on time-series collections, and the
  resulting move from database-enforced to application-level telemetry
  sync idempotency.

### Changed
- All three `/sync/*` endpoints now return `{"received": N, "inserted": M}`
  instead of `{"synced": N}` — the prior single field meant "processed"
  for sweep-sessions/obstacles but "newly inserted" for telemetry, an
  ambiguity a sync client couldn't reliably act on. No existing consumer
  depended on the old shape yet.
- Obstacle sync now preserves human review decisions (`review_status`,
  `reviewed_by`, `reviewed_at`, and a `permanent-confirmed` status) across
  a Pi re-sync, instead of a full-document replace silently reverting them.
- `MongoClient` now connects with `tz_aware=True`, so datetimes read back
  from MongoDB (e.g. `Rover.created_at`, `Obstacle.first_detected_at`)
  carry UTC tzinfo instead of coming back naive.

## [2.0.3] - 2026-09-23

### Added
- `docs/phase2/inputs/00-inbox.md` — first draft of offline Phase 2
  planning notes (mission packages, capability list, and related raw
  notes), captured unsorted. Triage into the numbered input files is
  deferred to the Phase 2 planning session.

## [2.0.2] - 2026-09-23

### Added
- `docs/phase2/inputs/` — structured templates for collecting Phase 2
  planning notes ahead of the design session: an inbox for unsorted
  notes, plus one file each for mission packages, capabilities,
  sensors/compute/electronics, physical platform updates, and
  constraints/assumptions/decisions/open questions. Items carry
  traceability IDs (`MP-`, `CAP-`, `SEN-`, `PLT-`, `Q-`, …) so each
  downstream item links back to the mission it supports. Phase 1
  baseline hardware constraints (GPIO usage, trimmed pins, power rails,
  open-loop drive) pre-filled from the repo.

## [2.0.1] - 2026-09-20

### Fixed
- Permanent fix for the servo header ground isolation defect (ADR 0002)
  applied to `pathfinder/kicad/papaya-pcb/papaya-pcb.kicad_pcb`: cut four
  zone cutouts into the `6V_POUR` zone on `B.Cu`, one behind each servo
  header GND pad, so the lower-priority `MASTER_GND` zone fills through
  to them on refill. Re-verified with `kicad-cli` DRC (0 violations,
  unconnected items down from 5 to 1 — the one remaining is the
  pre-existing, unrelated island near mounting hole `H1`) and with the
  same point-probe technique used to originally find the defect: real
  ground copper now reaches within 0.9mm of all four pads (previously
  nothing within 3–4mm), and the `6V_POUR` connection to each header's
  `PWR` pin was confirmed undisturbed.
- Gerbers and drill files in
  `pathfinder/kicad/papaya-pcb/gerbers/` regenerated to match. Board is
  ready to send to fab with this fix included — no more hand-wired ground
  jumpers needed on boards built from this revision.

### Added
- Minor `F.Silkscreen` identification text for a couple of components.

## [2.0.0] - 2026-09-19

Phase 1 baseline, pinned. Rover drives correctly end-to-end and this marks
the closing point of Phase 1 before Phase 2 (LIDAR/autonomy) design work
begins.

### Fixed
- Steering direction was reversed from stick input — this build's servo
  horns are mounted opposite the orientation the original channel-mapping
  math assumed. Fixed by inverting the steering channel reading in
  `firmware-elrs.ino`.

### Changed
- Throttle response: stick input is now squared (sign preserved) before
  driving the motors, giving finer control at low throttle instead of a
  1:1 linear mapping, plus an overall `THROTTLE_MAX` cap (0.6) as a
  top-speed limiter. Added after full-throttle testing was too aggressive
  off the line for indoor driving.

## [1.1.0] - 2026-09-19

Phase 1 complete: the rover drives under full ELRS control (steering,
throttle, spin-in-place all confirmed). Two real hardware defects were
found and fixed during final bring-up — full narrative in
[`docs/development-log.md`](docs/development-log.md#phase-1-bring-up-2026-08-20--2026-09-19).

### Added
- `docs/adr/0002-servo-header-ground-isolation.md` — architecture decision
  record for a PCB layout defect where all four servo header GND pads were
  physically isolated from the ground pour (boxed in by the 6V pour's
  territory), found via resistance testing and confirmed against the
  KiCad file itself. Documents the short-term hand-wired jumper fix in
  place now and the permanent routed-trace fix needed before any board
  reorder.
- `docs/build-guide.md` — start-from-scratch build guide covering BOM
  purchase through fabrication, assembly, firmware flashing, and bring-up
  testing, written to route around every pitfall hit during this build.

### Fixed
- Motor power distribution terminal block was wired incorrectly, shorting
  the motor supply; both motor channels now respond correctly to
  controller input.
- Servo header ground isolation (see ADR 0002 above) — hand-wired ground
  jumpers from `J8`'s ground terminal to each servo `GND` pin restore the
  connection the pour was supposed to provide.

### Changed
- `docs/superpowers/specs/2026-08-16-phase1-current-state.md` — all Phase 1
  exit criteria checked off except on-vehicle servo trim tuning (pending
  wheel attachment).

## [1.0.1] - 2026-09-09

### Added
- `docs/adr/0001-esp32-header-pin-trimming.md` — architecture decision
  record for trimming the ESP32 module's GPIO15/GPIO40 header pins (a pour
  boundary passes close enough between those two positions to risk an
  accidental short) instead of a full board respin or stripping every
  unused pin, and why the more aggressive option was rejected (mechanical
  retention risk on a full-size, vibration-exposed rover).
- `docs/servo-zeroing.md` — step-by-step procedure for flashing firmware
  and validating steering servo centering before horns are coupled to the
  steering linkage.

### Changed
- `docs/elrs-wiring.md` — reworked the ELRS binding instructions: the
  previously-documented "Method 1" binding-phrase flow doesn't work on
  this build's LiteRadio 2 SE (missing the BETAFPV Configurator
  compatibility sticker), so button-bind (chip-ID based) is now documented
  as the recommended method, with the binding-phrase flow kept only as
  reference and a callout on the root-cause gotcha (a receiver ever
  flashed with a binding phrase won't re-enter manual bind mode until that
  phrase is explicitly cleared).

## [1.0.0] - 2026-08-16

Baseline checkpoint. Version tracking starts here — prior work (wiring
model, KiCad PCB design, fabrication) predates this scheme and is described
in [`docs/development-log.md`](docs/development-log.md) rather than the
changelog.

### Added
- Semantic version tracking (`VERSION`, this changelog, git tags).
- `docs/superpowers/specs/2026-08-16-phase1-current-state.md` — Phase 1
  status snapshot and context anchor for the future Phase 2 (LIDAR/autonomy)
  brainstorming session.
- BOM entry for `U1` (UBEC 6V/8A), including Amazon ASIN.

### Changed
- Steering trims (`TRIM_LF/RF/LB/RB`) zeroed in
  `pathfinder/firmware-elrs/firmware-elrs.ino` to re-zero against the new
  Miuzei DS3218 servo horns; prior values were tuned for the previous
  servos and need on-vehicle re-tuning once horns are mounted.

### Status at this checkpoint
- PCB design complete, fabricated, boards received; premade Dupont headers
  acquired to replace hand-crimped connectors.
- Firmware bring-up in progress; servo re-trimming still required before
  servos/wheel assemblies can be connected for a full build.

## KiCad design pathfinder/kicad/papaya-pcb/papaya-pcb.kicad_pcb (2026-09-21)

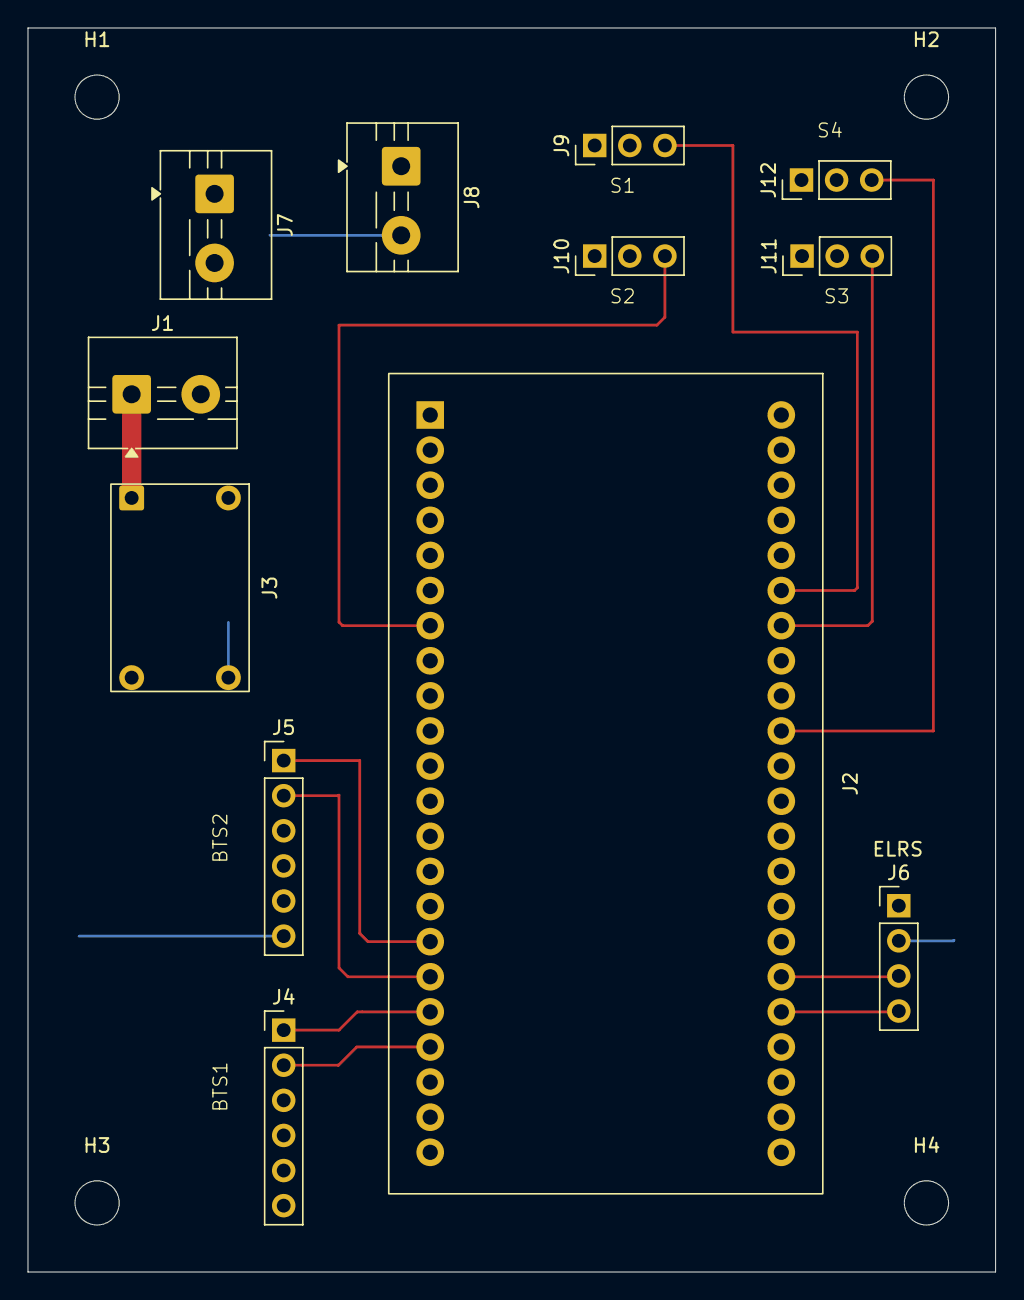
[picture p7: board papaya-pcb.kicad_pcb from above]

Board: 2 copper layers, 70.0 x 90.0 mm, 16 parts (0 on the bottom side), 14 nets.

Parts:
H1, H2, H3, H4: MountingHole_3.2mm_M3
J1: J1; TerminalBlock_MaiXu_MX126-5.0-02P_1x02_P5.00mm
J2: J_ESP32; ESP32S3_DevKit_2x1x22_split
J3: J_UBEC5V; UBEC_5V_3A_10x15mm
J4: J_BTS1; PinHeader_1x06_BTS_Signal
J5: J_BTS2; PinHeader_1x06_BTS_Signal
J6: J_ELRS; PinHeader_1x04_ELRS
J7: J_GND_MASTER; TerminalBlock_MaiXu_MX126-5.0-02P_1x02_P5.00mm
J8: J_UBEC6V; TerminalBlock_2Pos_UBEC6V
J9: J_S1; PinHeader_1x03_Servo
J10: J_S2; PinHeader_1x03_Servo
J11: J_S3; PinHeader_1x03_Servo
J12: J_S4; PinHeader_1x03_Servo

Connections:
/NET_A_BUS: J1.1 (Main_power_IN(feeds_U2)), J3.INP (U2_5V_IN-POS)
/NET_BTS1_PIN1_RPWM: J2.12 (ESP32_GPIO12-BTS1_pin1_R-PWM(socket)), J4.1 (BTS1_pin1-R-PWM)
/NET_BTS1_PIN2_LPWM: J2.13 (ESP32_GPIO13-BTS1_pin2_L-PWM(socket)), J4.2 (BTS1_pin2-L-PWM)
/NET_BTS2_PIN1_RPWM: J2.10 (ESP32_GPIO10-BTS2_pin1_R-PWM(socket)), J5.1 (BTS2_pin1-R-PWM)
/NET_BTS2_PIN2_LPWM: J2.11 (ESP32_GPIO11-BTS2_pin2_L-PWM(socket)), J5.2 (BTS2_pin2-L-PWM)
/NET_BUS_5V: J2.5V (ESP32_5V_IN_(socket_pin)), J3.OUTP (U2_5V_OUT_POS), J4.3 (BTS1_pin3-R-EN(5V)), J4.4 (BTS1_pin4-L-EN(5V)), J4.7 (BTS1_pin7-VCC(5V)), J5.3 (BTS2_pin3-R-EN(5V)), J5.4 (BTS2_pin4-L-EN(5V)), J5.7 (BTS2_pin7-VCC(5V)), J6.VCC (ELRS_VCC(5V))
/NET_BUS_6V: J8.OUTP (U1_6V_OUT(servo_+)), J9.PWR (S1_pin2-PWR(red)), J10.PWR (S2_pin2-PWR(red)), J11.PWR (S3_pin2-PWR(red)), J12.PWR (S4_pin2-PWR(red))
/NET_B_BUS: J1.2 (J1.2), J2.GND_1 (ESP32_ground,_near_5V_IN_(socket_pin)), J2.GND_2 (ESP32_ground_near_TX(socket_pin)), J3.INN (U2_5V_IN-NEG), J3.OUTN (U2_5V_OUT-NEG), J4.8 (BTS1_pin8-GND), J5.8 (BTS2_pin8-GND), J6.GND (ELRS_GND), J7.1 (Master_GND_OUT(to_B14)_1), J8.OUTN (U1_6V_OUT(servo_GND)), J9.GND (S1_pin1-GND(black)), J10.GND (S2_pin1-GND(black)), J11.GND (S3_pin1-GND(black)), J12.GND (S4_pin1-GND(black))
/NET_ELRS_RX: J2.21 (ESP32_GPIO21-ELRS_RX_white(socket)), J6.RX (ELRS_RX(white))
/NET_ELRS_TX: J2.47 (ESP32_GPIO47-ELRS_TX_green(socket)), J6.TX (ELRS_TX(green))
/NET_S1_SIG: J2.42 (ESP32_GPIO42-S1-RF_signal(socket)), J9.SIG (S1_pin3-SIG(white))
/NET_S2_SIG: J2.7 (ESP32_GPIO7-S2-LF-signal(socket)), J10.SIG (S2_pin3-SIG(white))
/NET_S3_SIG: J2.41 (ESP32_GPIO41-S3-RR_signal(socket)), J11.SIG (S3_pin3-SIG(white))
/NET_S4_SIG: J2.38 (ESP32_GPIO38-S4-LR_signal(socket)), J12.SIG (S4_pin3-SIG(white))

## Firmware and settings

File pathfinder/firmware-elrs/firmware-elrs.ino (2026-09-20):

#include <AlfredoCRSF.h>
#include <HardwareSerial.h>
#include <Adafruit_NeoPixel.h>

#define RX_PIN 47
#define TX_PIN 21

#define SERVO_RF_PIN 38
#define SERVO_RB_PIN 7
#define SERVO_LF_PIN 41
#define SERVO_LB_PIN 42

#define SERVO_FREQ 50
#define SERVO_RES 14

#define RGB_PIN 48
#define NUM_PIXELS 1

#define MOTOR_A_RPWM_PIN 12
#define MOTOR_A_LPWM_PIN 13

#define MOTOR_B_RPWM_PIN 10
#define MOTOR_B_LPWM_PIN 11

#define PWM_FREQ 10000
#define PWM_RES 8

static const int SERVO_CENTER_ANGLE = 90;
static const int SERVO_MAX_DELTA = 35;
static const int SERVO_HARDWARE_MIN = 5;
static const int SERVO_HARDWARE_MAX = 175;

// Trims temporarily zeroed for re-zeroing the new Miuzei DS3218 servo horns
// against a clean, untrimmed center. Old values (-10/-5) were tuned for the
// previous small servos and don't apply to the new hardware. Re-tune small
// (a few degrees) offsets here once horns are mounted and on-vehicle
// steering is verified straight.
int TRIM_LF = 0;
int TRIM_RF = 0;
int TRIM_LB = 0;
int TRIM_RB = 0;

// Throttle shaping: stick input is squared (sign preserved) before driving
// the motors, so small deflections near center produce proportionally less
// output than a 1:1 linear mapping -- finer control right off the line,
// full output still reachable at full stick. THROTTLE_MAX then scales the
// squared result as an overall top-speed cap, independent of the curve.
// Tune both down further (e.g. THROTTLE_MAX 0.4-0.5) if it's still too
// quick off the line.
const float THROTTLE_MAX = 0.6f;


bool connectToWiFi(const char* ssid, const char* pass, uint32_t timeoutMs);
void handlePostData();
void setSteering(float steer);
void setMotor(float throttle);
void writeServo(int pin, int angle);
void setSpin(float spinVal);
void led(int r, int g, int b);

HardwareSerial crsfSerial(2);
Adafruit_NeoPixel rgb(NUM_PIXELS, RGB_PIN, NEO_GRB + NEO_KHZ800);

AlfredoCRSF crsf;

void setup() {
  Serial.begin(115200);
  rgb.begin();
  rgb.show();
  led(255, 255, 255);

  ledcAttach(MOTOR_A_RPWM_PIN, PWM_FREQ, PWM_RES);
  ledcAttach(MOTOR_A_LPWM_PIN, PWM_FREQ, PWM_RES);
  ledcWrite(MOTOR_A_RPWM_PIN, 0);
  ledcWrite(MOTOR_A_LPWM_PIN, 0);

  ledcAttach(MOTOR_B_RPWM_PIN, PWM_FREQ, PWM_RES);
  ledcAttach(MOTOR_B_LPWM_PIN, PWM_FREQ, PWM_RES);
  ledcWrite(MOTOR_B_RPWM_PIN, 0);
  ledcWrite(MOTOR_B_LPWM_PIN, 0);

  ledcAttach(SERVO_RF_PIN, SERVO_FREQ, SERVO_RES);
  ledcAttach(SERVO_RB_PIN, SERVO_FREQ, SERVO_RES);
  ledcAttach(SERVO_LF_PIN, SERVO_FREQ, SERVO_RES);
  ledcAttach(SERVO_LB_PIN, SERVO_FREQ, SERVO_RES);

  setSteering(0.0f);

  crsfSerial.begin(420000, SERIAL_8N1, RX_PIN, TX_PIN);

  crsf.begin(crsfSerial);

  Serial.println("Starting receiver...");
}

void loop() {
  crsf.update();

  if (crsf.isLinkUp()) {
    led(0, 255, 0);

    int rawSteering = crsf.getChannel(1);
    int rawThrottle = crsf.getChannel(3);
    int rawSpin = crsf.getChannel(4);

    // Inverted vs. a naive channel reading -- this build's servo horns are
    // mounted opposite the orientation the steering math assumes, so
    // left/right stick was driving the wheels the wrong way.
    float steeringVal = (1500 - rawSteering) / 500.0;
    float throttleVal = (rawThrottle - 1500) / 500.0;
    float spinVal = (rawSpin - 1500) / 500.0;

    float deadzone = 0.1;

    if (abs(spinVal) > deadzone && abs(throttleVal) < deadzone && abs(steeringVal) < deadzone) {
      setSpin(spinVal);
    } else {
      if (abs(steeringVal) < deadzone) steeringVal = 0;
      if (abs(throttleVal) < deadzone) throttleVal = 0;

      float throttleSign = (throttleVal < 0) ? -1.0f : 1.0f;
      throttleVal = throttleSign * throttleVal * throttleVal * THROTTLE_MAX;

      setSteering(steeringVal);
      setMotor(throttleVal);
    }
  } else {
    led(255, 0, 0);
    Serial.println("Waiting for transmitter connection...");
  }

  delay(20);
}

void writeServo(int pin, int angle) {
  angle = constrain(angle, SERVO_HARDWARE_MIN, SERVO_HARDWARE_MAX);
  int duty = map(angle, 0, 180, 410, 1966);

  ledcWrite(pin, duty);
}

void setSteering(float steer) {
  steer = constrain(steer, -1.0f, 1.0f);
  int delta = steer * SERVO_MAX_DELTA;

  int lf_angle = SERVO_CENTER_ANGLE + TRIM_LF + delta;
  int rf_angle = SERVO_CENTER_ANGLE + TRIM_RF + delta;
  int lb_angle = SERVO_CENTER_ANGLE + TRIM_LB - delta;
  int rb_angle = SERVO_CENTER_ANGLE + TRIM_RB - delta;

  writeServo(SERVO_LF_PIN, lf_angle);
  writeServo(SERVO_RF_PIN, rf_angle);
  writeServo(SERVO_LB_PIN, lb_angle);
  writeServo(SERVO_RB_PIN, rb_angle);
}

void setMotor(float throttle) {
  throttle = constrain(throttle, -1.0f, 1.0f);

  int pwmValue = abs(throttle) * 255;

  if (throttle > 0.05) {
    ledcWrite(MOTOR_A_RPWM_PIN, 0);
    ledcWrite(MOTOR_A_LPWM_PIN, pwmValue);

    ledcWrite(MOTOR_B_RPWM_PIN, pwmValue);
    ledcWrite(MOTOR_B_LPWM_PIN, 0);
  } else if (throttle < -0.05) {
    ledcWrite(MOTOR_A_RPWM_PIN, pwmValue);
    ledcWrite(MOTOR_A_LPWM_PIN, 0);

    ledcWrite(MOTOR_B_RPWM_PIN, 0);
    ledcWrite(MOTOR_B_LPWM_PIN, pwmValue);
  } else {
    ledcWrite(MOTOR_A_RPWM_PIN, 0);
    ledcWrite(MOTOR_A_LPWM_PIN, 0);

    ledcWrite(MOTOR_B_RPWM_PIN, 0);
    ledcWrite(MOTOR_B_LPWM_PIN, 0);
  }
}

void setSpin(float spinVal) {
  spinVal = constrain(spinVal, -1.0f, 1.0f);

  int angle = 45;

  int lf = SERVO_CENTER_ANGLE + TRIM_LF + angle;
  int rf = SERVO_CENTER_ANGLE + TRIM_RF - angle;
  int lb = SERVO_CENTER_ANGLE + TRIM_LB - angle;
  int rb = SERVO_CENTER_ANGLE + TRIM_RB + angle;

  writeServo(SERVO_LF_PIN, lf);
  writeServo(SERVO_RF_PIN, rf);
  writeServo(SERVO_LB_PIN, lb);
  writeServo(SERVO_RB_PIN, rb);

  int pwm = abs(spinVal) * 255;

  if (spinVal < 0) {
    ledcWrite(MOTOR_A_RPWM_PIN, 0);
    ledcWrite(MOTOR_A_LPWM_PIN, pwm);

    ledcWrite(MOTOR_B_RPWM_PIN, 0);
    ledcWrite(MOTOR_B_LPWM_PIN, pwm);

  } else {
    ledcWrite(MOTOR_A_RPWM_PIN, pwm);
    ledcWrite(MOTOR_A_LPWM_PIN, 0);
    ledcWrite(MOTOR_B_RPWM_PIN, pwm);
    ledcWrite(MOTOR_B_LPWM_PIN, 0);
  }
}

void led(int r, int g, int b) {
  rgb.setPixelColor(0, rgb.Color(r, g, b));
  rgb.show();
}

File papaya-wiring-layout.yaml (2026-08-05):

# =============================================================================
# Papaya Pathfinder — System Wiring Layout
# =============================================================================
# This file describes the FULL electrical system, not just the custom PCB:
# battery, protection/switching, terminal blocks, off-board modules (ESP32,
# motor drivers, motors, servos, ELRS receiver, UBECs...) and the custom board
# itself. The goal is a single source of truth that can drive:
#   - a KiCad schematic (pathfinder/kicad/papaya-pcb/papaya-pcb.kicad_sch)
#   - a KiCad PCB layout (pathfinder/kicad/papaya-pcb/papaya-pcb.kicad_pcb)
#   - build/wiring documentation
#
# STRUCTURE
#   system      -- overall metadata
#   components  -- every physical part in the system (see componentType below)
#   connections -- every wire/trace between two connection points
#
# componentType values:
#   battery       - power source (e.g. LiPo pack)
#   fuse          - inline protection device
#   switch        - power switch / disconnect
#   terminalBlock - screw/terminal block used to distribute or join wires
#   offBoard      - any module NOT on the custom PCB (ESP32, motor driver,
#                   motor, servo, UBEC, receiver, antenna, connector, etc.)
#                   Use ONE component entry per physical part (e.g.
#                   bts7960-1, bts7960-2, motor-lf, motor-rf, servo-1...),
#                   not one entry per part type.
#   board         - the custom PCB itself (pathfinder/kicad/papaya-pcb).
#                   Once real KiCad connectors/designators exist, name each
#                   connectionPoint after its KiCad ref+pin (e.g. "J1.1",
#                   "J2.3") so this file can be cross-checked against the
#                   .kicad_sch netlist.
#
# Each component lists its own `connectionPoints` — the specific pins,
# terminals, pads, or screw positions that can be wired to. `connections`
# then references those points by (componentId, pointId) pairs.
#
# KICAD PIN NAME (generator output only — don't hand-author this)
#   `label` is the full descriptive text for docs/comments; the generated
#   schematic uses it as each pin's on-screen name, which gets unreadable
#   fast on symbols with many pins. Once you've tightened pin names up in
#   KiCad's Symbol Editor for legibility, run
#   `python pathfinder/kicad/scripts/sync_pin_names.py` to pull those
#   shortened names back into each connectionPoint's `kicadPinName` field
#   (added alongside `label`, which is left untouched). Regenerating the
#   schematic afterward will use `kicadPinName` when present instead of
#   `label`, so your legibility pass survives a regeneration.
#
# CONNECTION MEDIUM (wire vs. PCB trace)
#   Every entry in `connections` has a `medium` describing HOW the two
#   points are physically joined:
#     kind: wire  - a physical wire (off-board, or terminal-block-to-board).
#                   Fields: color, gauge, lengthMm.
#     kind: trace - a copper trace on the custom PCB. Only valid when BOTH
#                   endpoints are on the `board` component. Fields: layer
#                   (e.g. "F.Cu"), widthMm. There's no "color" for a trace —
#                   this is where the abstraction shifts from a physical
#                   wire you cut/crimp to a route KiCad draws for you.
#   You don't need to pick trace-vs-wire yourself for on-board routing
#   beyond marking it `kind: trace`; once the schematic/PCB exists, the
#   actual copper path is whatever KiCad routes, not something you specify
#   here — this file just records the intended net.
#
# CONNECTOR TYPE (board connectionPoints only)
#   A board connectionPoint can optionally carry a `connector` block
#   describing what physical part needs to be populated there — this is
#   what tells KiCad (and you, at the workbench) whether a point is a
#   screw terminal, a solder pad, a pin header, or a socket header:
#     connector: { type: screwTerminal | solderPad | pinHeader | socketHeader, notes: "" }
#   Leave it off if you haven't decided yet; add it once you know what
#   needs to be soldered/mounted at that point.
#
# BONDED GROUPS (bus bars / ganged terminal positions)
#   Some components (most often a terminalBlock used as a distribution
#   bus) have several connectionPoints permanently tied together with a
#   hardwire jumper/bus bar, so they're all one electrical net. Instead of
#   writing a chain of jumper `connections`, list the tied points once in
#   that component's optional `bondedGroups`. Individual wires (e.g. the
#   feed-in, or the leg to one motor) still attach to a single point within
#   the group via a normal `connections` entry — the group just says "these
#   points are already the same node."
#   The same mechanism works on `board-main` for an on-board power/ground
#   bus (a copper pour or wide trace tying many pads to one net) — see
#   `bus-5v` / `bus-gnd` below. No individual point-to-point `connections`
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

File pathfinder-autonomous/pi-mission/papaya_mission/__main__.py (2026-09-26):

"""CLI entrypoint for the Mission Runtime. Wires MissionRuntime with
SimulatedSensorHub / a placeholder Esp32Link until real hardware
drivers exist (future hardware-integration pass -- see design notes'
Architecture & file structure)."""
from __future__ import annotations

import logging
import time

from papaya_mission.esp32_link import FakeEsp32Link
from papaya_mission.position_fusion import ImuReading
from papaya_mission.runtime import MissionRuntime
from papaya_mission.runtime_config import TICK_INTERVAL_S, load_runtime_settings
from papaya_mission.sensor_hub import SimulatedSensorHub

logging.basicConfig(level=logging.INFO)
logger = logging.getLogger("papaya_mission.runtime")


def main() -> None:
    settings = load_runtime_settings()
    sensor_hub = SimulatedSensorHub(
        ImuReading(heading_deg=0.0, forward_acceleration_mps2=0.0, timestamp=time.monotonic())
    )
    esp32_link = FakeEsp32Link()

    runtime = MissionRuntime(
        rover_id=settings.rover_id,
        backend_base_url=settings.backend_base_url,
        local_db_path=settings.local_db_path,
        sensor_hub=sensor_hub,
        esp32_link=esp32_link,
    )
    runtime.startup()
    logger.info("Mission Runtime started for rover %s", settings.rover_id)

    while True:
        tick_started = time.monotonic()
        try:
            runtime.tick()
        except Exception:
            # Outermost-loop catch-all, and deliberately broader than the
            # per-subsystem guards inside runtime.py. Those stay narrow on
            # purpose: a guard wrapped tightly around one sensor read or one
            # command should not also swallow a logic bug in the code around
            # it. Here at the top of an unattended, always-on rover process
            # the tradeoff inverts -- a genuine uncaught bug that kills the
            # process leaves the rover stranded mid-field with no telemetry
            # and no command channel, which is strictly worse than logging
            # the traceback and attempting the next tick. The traceback is
            # logged in full (exc_info) precisely so this cannot hide a bug:
            # a repeating exception here is a loud, diagnosable signal, not a
            # silent pass.
            logger.exception("tick raised -- logged and continuing to the next tick")
        tick_duration_s = time.monotonic() - tick_started
        if tick_duration_s > TICK_INTERVAL_S:
            logger.warning(
                "tick took %.3fs, over the %.3fs budget (TICK_HZ) -- see design notes' Scaling note",
                tick_duration_s, TICK_INTERVAL_S,
            )
        time.sleep(max(0.0, TICK_INTERVAL_S - tick_duration_s))


if __name__ == "__main__":
    main()

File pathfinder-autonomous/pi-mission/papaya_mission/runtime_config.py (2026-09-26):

"""Runtime-wide named constants and .env-loaded settings for Mission
Runtime. See design notes: Decisions made so far, Global Constraints.
"""
from __future__ import annotations

import os
from dataclasses import dataclass

from dotenv import load_dotenv

load_dotenv()

# --- Loop timing -----------------------------------------------------------
# All overridable by editing this file. See design notes' "Scaling note"
# for the revisit trigger if TICK_HZ's 100ms budget ever gets tight.
TICK_HZ = 10
TICK_INTERVAL_S = 1.0 / TICK_HZ
COMMAND_POLL_INTERVAL_S = 1.0
TELEMETRY_SAMPLE_INTERVAL_S = 5.0

# --- GPS-loss safety thresholds ----------------------------------------------
# Whichever is hit first triggers stop_and_alert -- see
# papaya_mission.gps_loss_decision.decide_gps_loss_response.
GPS_LOSS_GRACE_PERIOD_S = 30.0
GPS_LOSS_MAX_ERROR_RADIUS_M = 5.0

# --- Coverage-pattern input ---------------------------------------------------
# Ultrasonic sensor's effective detection width in meters, sets row
# spacing (papaya_mission.row_spacing). PLACEHOLDER: the actual
# ultrasonic sensor part hasn't been selected yet (open item in the MP-1
# design spec's BOM) -- update this once it is.
SENSOR_DETECTION_WIDTH_M = 2.0

# --- Telemetry expected-metric keys -------------------------------------------
# Telemetry metric keys MP-1 always expects, independent of the sensor
# manifest (which lists physical sensors like "gps"/"imu"/"bump", not
# derived/computed telemetry fields like these). Unioned with the
# manifest in MissionRuntime.startup() to build the full expected set.
#
# build_telemetry_record treats the expected set as both floor AND
# ceiling: anything absent is stored as "missing", anything present in
# the readings but NOT expected is silently dropped. So a key that isn't
# listed here (and isn't a manifest sensor) never reaches the backend.
#
# Per-servo keys are the one thing that cannot live in this static set:
# they are named `servo_{id}_deg` from whatever ids the ESP32 actually
# reports in DriveStatus.servo_positions_deg on a given tick, which is
# not knowable ahead of time (and will change once the steering-servo
# naming convention is settled). _sample_telemetry_if_due therefore
# extends this set on the fly with that tick's real servo keys before
# calling build_telemetry_record. Do not try to pre-enumerate servo
# names here.
MP1_EXPECTED_METRICS = {
    "position",
    "position_uncertainty_m",
    "heading_deg",
    "error_radius_m",
    "nav_mode",
    "waypoint_index",
    "throttle_position",
    "mission_alert",
}


@dataclass(frozen=True)
class RuntimeSettings:
    rover_id: str
    backend_base_url: str
    local_db_path: str


def load_runtime_settings() -> RuntimeSettings:
    """Reads ROVER_ID/BACKEND_BASE_URL/LOCAL_DB_PATH from the environment
    (via .env, same convention as pathfinder-autonomous/backend/). Raises
    KeyError if any is missing -- fail loudly rather than silently
    defaulting to a placeholder that could mask a real misconfiguration.
    """
    return RuntimeSettings(
        rover_id=os.environ["ROVER_ID"],
        backend_base_url=os.environ["BACKEND_BASE_URL"],
        local_db_path=os.environ["LOCAL_DB_PATH"],
    )

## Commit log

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2026-07-27 Add personal README, dev log, and KiCad schematic generator
    Split docs into a fork-specific README (this build's hardware/docs/tooling)
    and an archived upstream README for attribution. Adds development-log.md
    summarizing the wiring model and generator work. Extends
    papaya-wiring-layout.yaml with real wire gauges and the UBEC 6V/servo/motor
    wiring, and adds generate_schematic.py, which forward-engineers a fully
    wired starter KiCad schematic from that YAML (validated against KiCad 10
    with zero ERC errors).
    [papaya-pcb.kicad_sch]
2026-07-29 Reset generated schematic after manual KiCad edit
    Regenerated papaya-pcb.kicad_sch from the wiring YAML to restore the
    label-based net connections after a manual edit (drawn wire in place of
    a net label) diverged from the generator's output. kicad_pro now
    registers the schematic sheet (populated by KiCad on open/save).
    [papaya-pcb.kicad_sch]
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2026-08-03 Sync KiCad pin names to YAML; fix UBEC5V input net; add sync tooling
    Added a kicad_sexpr.py (S-expression tokenizer/parser) and
    sync_pin_names.py (pure text-patcher, insert-only so existing YAML
    comments/formatting survive) to pull pin names tightened up in KiCad's
    Symbol Editor back into papaya-wiring-layout.yaml as a new kicadPinName
    field per connectionPoint, alongside the existing descriptive label.
    generate_schematic.py now prefers kicadPinName when present.
    Also fixes a real wiring bug found via netlist diff against the YAML:
    J1 pin 2 (board ground-in) and J3 pin INP (UBEC 5V/3A positive input) had
    been wired to each other instead of to their correct nets. Verified via
    kicad-cli expor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
    [papaya-pcb.kicad_sch]
2026-08-05 Assign real footprints to all board connectors; add BOM
    Adds pathfinder/BOM.md with actual Amazon ASINs and measured dimensions
    for the on-board parts (ESP32-S3 dev board, UBEC 5V/3A). Matched 11 of
    12 board connectors against real footprints in the installed KiCad 10
    library; the UBEC 5V/3A pads have no standard match, so built a custom
    footprint (papaya-pcb.pretty/UBEC_5V_3A_10x15mm.kicad_mod) from measured
    pin spacing, registered via a new project fp-lib-table, and corrected
    its INP/INN/OUTP/OUTN pad placement per physical part orientation.
    assign_footprints.py (new, insert-only text patcher like the other
    sync tools) applied all 12 assignments directly to both the wiring YAML
    (connector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
    [papaya-pcb.kicad_sch]
2026-08-05 Replace ESP32 footprint with real split-header layout; add board outline
    The library footprint (PinSocket_2x22, one compact block) was wrong for
    this board -- the real ESP32-S3 dev board uses two separate 1x22 header
    rows (Espressif's J1/J3) spaced across the board width, not one dual-row
    connector. Built a custom footprint (ESP32S3_DevKit_2x1x22_split) with
    all 44 physical positions for correct socket-strip fit, with the 13
    actually-wired signals placed at their real positions per Espressif's
    published ESP32-S3-DevKitC-1 pin tables (cross-checked against this
    project's own early build notes -- the 5V/ground adjacencies matched
    exactly). Row spacing (25.75mm) is the midpoint of a physical ca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
    [papaya-pcb.kicad_pcb, papaya-pcb.kicad_sch]
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2026-08-06 Complete first full routing pass: power/ground pours + all signal traces
    Board is now fully routed and verified: three copper pours (5V, 6V,
    ground) on B.Cu with priority ordering resolved, all 11 remaining
    point-to-point signal traces (servo SIG, BTS PWM pairs, ELRS TX/RX,
    battery feed) routed on F.Cu, and layout rearranged (J4/J5 swap,
    servo repositioning) for cleaner trace paths without vias.
    Verified clean: 0 DRC violations, and a full net-by-net comparison of
    the actual board against the wiring YAML's 20 expected nets shows zero
    divergence -- every connection from the original design matches the
    routed board exactly. Physically test-fit against a printed 1:1 scale
    layout, confirmed cor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
    [papaya-pcb.kicad_pcb]
2026-08-06 Add M3 mounting holes at PCB corners
    Four 3.2mm (M3 clearance) NPTH mounting holes (H1-H4) placed at the
    board corners for chassis mounting. J7 and the servo header cluster
    (J9-J12) were nudged to clear the new holes; zones refilled and
    re-verified via DRC (0 violations).
    [papaya-pcb.kicad_pcb]
2026-08-06 Regenerate Gerbers/drill files with mounting holes included
    Fab-ready output for the final board revision: J7/servo cluster
    repositioned to clear the new corner mounting holes, drill file now
    includes the 4 NPTH M3 clearance holes (T4, 3.200mm).
    [papaya-pcb-B_Cu.gbl, papaya-pcb-B_Mask.gbs, papaya-pcb-B_Silkscreen.gbo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]
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2026-08-17 Add U1 UBEC BOM entry; zero steering trims for DS3218 re-zero
    U1 (6V/8A UBEC) added to the BOM for parts lookup. Steering trims reset
    to 0 across all four servos ahead of re-zeroing against the new Miuzei
    DS3218 horns -- prior values were tuned for the old servos.
    [firmware-elrs.ino]
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2026-09-20 Fix reversed steering, tame throttle response; pin Phase 1 as v2.0.0
    Steering was inverted vs. stick input because this build's servo horns
    are mounted opposite the original channel-mapping assumption. Throttle
    now uses a squared response curve plus an overall cap (THROTTLE_MAX=0.6)
    after full-linear throttle proved too aggressive for indoor driving.
    Both verified working on hardware. This closes out Phase 1.
    [firmware-elrs.ino]
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2026-09-21 Apply permanent servo-ground fix to PCB, regenerate Gerbers; v2.0.1
    Cuts four zone cutouts into the 6V_POUR zone on B.Cu, one behind each
    servo header GND pad (J9-J12), so MASTER_GND's lower fill priority
    connects through on refill -- resolves ADR 0002 without a layer jump or
    routing around signal traces. Re-verified via kicad-cli DRC (0
    violations, unconnected items 5 -> 1, the remainder being a pre-existing
    unrelated island) and the same point-probe technique that originally
    found the defect (real ground copper now within 0.9mm of all four pads;
    6V supply to each PWR pin confirmed undisturbed).
    Also includes minor F.Silkscreen identification text. Gerbers/drill
    files regenerated to match.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
    [papaya-pcb-B_Cu.gbl, papaya-pcb-B_Mask.gbs, papaya-pcb-B_Silkscreen.gbo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]
2026-09-21 Replace CLI-approximated Gerbers with GUI-exported fab set
    kicad-cli can't regenerate the .gbrjob file, so the previous commit's
    Gerbers used CLI-only output as a best-effort stand-in. These are now
    replaced with the actual GUI Plot export (File > Fabrication Outputs),
    which includes an accurate, current .gbrjob and adds the F/B Paste
    layers. Drill files are unchanged (still valid -- the ground-cutout fix
    didn't add/remove any holes). Consolidated into gerbers/ as the single
    source of fab output; re-zipped to match.
    [papaya-pcb-B_Cu.gbr, papaya-pcb-B_Mask.gbr, papaya-pcb-B_Paste.gbr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]
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2026-09-25 Add guard against non-positive row_spacing_m in generate_coverage_pattern
    Fixes a critical issue where row_spacing_m <= 0 causes an infinite loop
    in the lawnmower coverage-pattern algorithm. Added ValueError guard at
    function entry point and corresponding tests for zero and negative inputs.
    - Add input validation check: raises ValueError if row_spacing_m <= 0
    - Add test_non_positive_row_spacing_raises_value_error for row_spacing_m=0.0
    - Add test_negative_row_spacing_raises_value_error for row_spacing_m=-5.0
    All existing tests still pass.
    [coverage_pattern.py, test_coverage_pattern.py]
2026-09-25 Return coverage pattern as legs, not a flat waypoint list
    generate_coverage_pattern silently concatenated every row segment into
    one flat list, so a consumer walking it in order would drive straight
    from the end of one segment to the start of the next -- cutting through
    the very exclusion zone that split the row (3 of 20 waypoints on the
    POND fixture formed pond-crossing legs).
    It now returns list[list[tuple[float, float]]]: one leg per contiguous
    drivable segment. Consumers route between legs themselves; this library
    does no road-network routing, per the design spec's Route Planning scope.
    Tests assert the real invariant the old ones missed: no consecutive pair
    of points *within* a leg in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
    [coverage_pattern.py, test_coverage_pattern.py, test_integration.py]
2026-09-25 Distribute coverage rows across the full field height
    Rows stepped south-to-north from miny + spacing/2 and stopped once lat
    passed maxy, silently dropping any remainder shorter than one row
    spacing: a 40m-tall field at 30m spacing got a single row at 15m,
    leaving 62% of the field uncovered, and a field under half a spacing
    tall returned zero waypoints with no error at all.
    Row count is now ceil(height / spacing) (minimum 1) and the rows are
    spread evenly over the full height, so the last row always lands inside
    the field. Deriving each latitude from its row index also removes the
    float drift of repeated `lat += row_spacing_deg` accumulation.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
    [coverage_pattern.py, test_coverage_pattern.py]
2026-09-25 Measure exclusion intrusion depth in a local meters frame
    exclusion_intrusion_depth_m had two bugs:
    1. It scaled a raw degree-space distance by METERS_PER_DEGREE_LAT,
    ignoring that a degree of longitude spans only
    METERS_PER_DEGREE_LAT * cos(lat). At latitude 38 a pure east-west
    intrusion reported 11.132m where the truth is 8.772m -- 27% too deep.
    2. It measured against `.exterior`, the outer ring only, so a position
    standing just inside a donut-shaped exclusion's hole wall got its
    distance to the far outer boundary instead: 1046m reported vs 8.77m
    actual.
    Both are fixed by transforming the point and the polygon into a local
    meters frame (longitude scaled by cos of the po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
    [exclusion_check.py, test_exclusion_check.py]
2026-09-25 Harden position_fusion against lat/lon swaps; document velocity reset
    Three changes to position_fusion.py:
    1. lon/lat mixup bridge. This module uses named .lat/.lon fields while
    coverage_pattern and exclusion_check take raw (lon, lat) tuples, so
    wiring them together invited a silent swap -- a swapped tuple still
    builds a valid Point, it is just never inside any exclusion zone.
    PositionEstimate.as_lon_lat() now provides the tuple in the right
    order, and GpsFix/ImuReading/PositionEstimate are
    @dataclass(frozen=True, kw_only=True) so positional construction
    (GpsFix(*lon_lat_tuple, ...)) raises TypeError instead of swapping
    quietly. Every existing call site already used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
    [position_fusion.py]
2026-09-25 feat(pi-mission): extract geo_utils, add heading tracking and input validation
    Task 1 of the MP-1 Obstacle Detection & Classification plan. Extracts
    METERS_PER_DEGREE_LAT and adds project_position()/flat_earth_distance_m()
    to a new geo_utils.py shared by position_fusion, coverage_pattern, and
    exclusion_check (mechanical import swap only in the latter two -- their
    post-fix-wave logic, segmented legs, row_spacing guard, even row
    distribution, local-meters exclusion depth -- is untouched).
    PositionEstimate gains heading_deg, tracked from ImuReading.heading_deg
    and left alone by GPS fixes, so a later task can combine mast-relative
    bearings with the rover's own heading. GpsFix/ImuReading now val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
    [coverage_pattern.py, exclusion_check.py, geo_utils.py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]
2026-09-25 Deduplicate lat/lon projection math in position_fusion
    on_imu_reading had its own inline copy of the projection formula that
    geo_utils.project_position already implements. The two implementations
    happened to agree, but nothing kept them in sync -- a future fix to one
    would not have propagated to the other, defeating the point of
    extracting geo_utils as the shared geometry helper.
    Replace the inline delta_lat/delta_lon computation with a call to
    project_position(self._lat, self._lon, reading.heading_deg, distance_m),
    which already takes lat/lon as plain parameters and so can't have the
    pre-move-vs-post-move latitude ordering bug by construction. Pure
    refactor: test_longitude_update_uses_the_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
    [position_fusion.py]
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2026-09-26 Make obstacle reconciliation greedy nearest-first and one-to-one
    _find_nearby_match let a single fresh detection confirm every known
    obstacle within match_radius_m of it, so two known posts 2m apart with
    only one re-detected both reported confirmed and the missing one never
    surfaced as a discrepancy.
    Matching now ranks all (known, fresh) pairs inside the radius by distance
    and greedily claims closest-first, dropping both sides of each claimed
    pair. Bookkeeping is by list index because Obstacle is a frozen dataclass
    and distinct obstacles with identical fields compare equal.
    Also adds ReconciliationResult.new_detections: fresh detections that
    matched nothing known, which the one-to-one pass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
    [resume_validation.py]
2026-09-26 Import METERS_PER_DEGREE_LAT from its real home, not via position_fusion
    After the projection math moved into geo_utils, position_fusion.py kept
    importing METERS_PER_DEGREE_LAT without using it in its own body -- the
    import survived only because test_position_fusion.py imported the
    constant back out of position_fusion as an accidental re-export. Any
    linter removing the 'unused' import would have broken that test.
    The test now imports the constant from papaya_mission.geo_utils and the
    dead import is gone. coverage_pattern.py and exclusion_check.py import
    the same constant but genuinely use it, so they are unaffected.
    [position_fusion.py]
2026-09-26 Make PositionFusion tuning parameters keyword-only
    initial_heading_deg was inserted between initial_fix and the pre-existing
    drift_rate_m_per_s, so PositionFusion(fix, 0.3) silently set a heading
    where it used to set a drift rate -- the exact silent-positional-mixup
    class of bug the kw_only dataclasses in this module were written to
    prevent.
    initial_heading_deg and drift_rate_m_per_s are now keyword-only.
    initial_fix stays positional: every call site in the codebase already
    passes it that way and passes both tuning params by keyword, so nothing
    needed updating.
    [position_fusion.py]
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2026-09-26 fix(pi-mission): guard complete() against double-completion and non-contiguous patterns
    complete() only checked is_fully_covered, so it silently succeeded when
    called twice or when called directly from INTERRUPTED (bypassing
    resume()). Add a status guard requiring IN_PROGRESS before completing.
    mark_waypoint_complete validated only the arithmetic sequence of orders,
    not that a Waypoint with that order exists in pattern. Add __post_init__
    to SweepSession requiring contiguous, zero-indexed waypoint orders, so
    is_fully_covered and remaining_waypoints can never disagree.
    Also drop the unused `field` import from dataclasses.
    [sweep_session.py]
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2026-09-26 Fix GPS loss decision boundary semantics: use >= instead of >
    Change both boundary conditions in decide_gps_loss_response to use >= (inclusive)
    so that hitting a threshold exactly triggers stop_and_alert immediately, matching
    the more conservative exclusion-zone decision precedent.
    - Updated docstring to reflect inclusive boundary conditions
    - Changed seconds_since_last_fix > grace_period_s to >=
    - Changed current_error_radius_m > max_error_radius_m to >=
    - Added test_exactly_at_grace_period_boundary_stops: verify exact grace period triggers stop
    - Added test_exactly_at_error_radius_boundary_stops: verify exact error radius triggers stop
    All 83 tests pass (81 existing + 2 new boundary test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
    [gps_loss_decision.py, test_gps_loss_decision.py]
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2026-09-26 fix(pi-mission): make SweepSession leg-boundary-aware and validate its bounds
    generate_coverage_pattern returns legs -- contiguous drivable polylines
    split wherever an exclusion zone interrupts a row -- but SweepSession's
    flat waypoint list had no way to represent those boundaries, so every
    consumer flattened the legs and lost exactly the information that says
    "do not drive straight from here to there".
    - Waypoint gains leg_index (default 0, so existing construction is
    unchanged), and SweepSession.from_legs() builds a session straight
    from generate_coverage_pattern()'s output with the boundaries intact.
    - Reject an empty pattern: is_fully_covered was vacuously True for it,
    so complete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
    [sweep_session.py, test_mission_flow_integration.py]
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2026-09-26 fix(pi-mission): refresh position/confidence/detection_method on obstacle re-save
    save_obstacle's ON CONFLICT DO UPDATE clause only refreshed status,
    last_confirmed_at, and synced_at, silently dropping refined
    position/confidence/detection_method on re-detection of an existing
    obstacle id (e.g. resume-validation tightening a GPS fix, or a second
    classification pass). Expand the UPDATE SET to also refresh
    position_lon, position_lat, position_uncertainty_m,
    classification_confidence, and detection_method.
    [local_store.py, test_local_store.py]
2026-09-26 Fix: refresh type in save_obstacle upsert on conflict
    Add type to the ON CONFLICT(id) DO UPDATE SET clause so that obstacle
    type updates are captured when an obstacle is refined (e.g. reclassified
    from barrel to utility_pole). Without this, the type would stale.
    Also extend test_saving_an_obstacle_again_refreshes_position_and_confidence
    to verify type updates alongside position and classification_confidence.
    [local_store.py, test_local_store.py]
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2026-09-26 Harden pi-mission local store and sync client
    Three review findings from the final whole-branch review of the MP-1 Pi
    Local Store & Sync Client plan:
    1. sync_client tests never asserted the request body, only the URL -- so
    the one seam this plan exists to get right (does our JSON match what
    the backend's /sync/* Pydantic models expect) was unverified. Added a
    body-capturing MockTransport helper and an exact wire-shape assertion
    per entity: obstacle, sweep session, telemetry. All three passed on
    first run, confirming the existing _*_to_wire functions were already
    correct -- the gap was purely in verification.
    2. local_store had only list_unsynced_* accessors, so a record b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
    [local_store.py, sync_client.py, test_local_store.py]
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2026-09-26 fix(pi-mission): decouple resume-validation reconciliation from detection
    Resume-validation reconciliation was entangled with _detect_obstacles'
    paired-detection branch, causing two bugs:
    1. Duplicate rows. A paired detection was persisted immediately with a
    fresh id, then reconciliation upserted the same physical obstacle
    again under the known obstacle's id -- two rows for one obstacle,
    both synced to the backend, with the orphan reported as a bogus
    "vanished" discrepancy on the next resume pass.
    2. Reconciliation was unreachable without a detection. It was only ever
    called from inside the paired-detection branch, so arriving at the
    resume target having detected nothing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
    [runtime.py]
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2026-09-26 feat(pi-mission): add Home-return sync, CLI entrypoint, and end-to-end test
    Task 9 of the MP-1 Mission Runtime plan. Wires stop_sweep/abort_home and
    full-coverage completion into sync_client.sync_all at the Home-return
    checkpoint, adds the python -m papaya_mission CLI entrypoint (placed at
    papaya_mission/__main__.py so that invocation actually resolves), and
    documents both in the pi-mission README.
    [__main__.py, runtime.py]
2026-09-26 fix(pi-mission): fault-isolate backend/sync calls in the tick loop
    The Global Constraints require that a failure polling commands or
    syncing to the backend never stop the mission -- log it and continue.
    Neither _poll_and_handle_commands_if_due nor _home_return_sync had any
    try/except around their network calls, so a dropped connection or a
    backend 5xx during a routine command poll or a Home-return sync would
    propagate uncaught out of tick() and kill the unattended rover process.
    Wrap poll_commands, and each command's handle+ack pair (per-command,
    inside the loop, so one command's ack failure doesn't block the rest
    of the batch), plus sync_client.sync_all in _home_return_sync, in
    try/except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
    [runtime.py]
2026-09-26 fix(pi-mission): dispatch start_sweep commands and widen fault isolation
    _handle_command had no start_sweep branch and no else: a start_sweep
    polled from the backend fell through every branch and was acked as if
    handled, so the rover reported active with no sweep ever starting and
    nothing logged. Add the branch, plus an else that warns on any
    unrecognized type.
    Broaden the per-command guard from httpx.HTTPError to Exception --
    KeyError/ValueError/shapely errors are all reachable from one malformed
    command and none is an HTTP error -- and wrap __main__'s tick() call so
    an uncaught bug logs a traceback and retries next tick instead of
    stranding an unattended rover mid-field.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
    [__main__.py, runtime.py]
2026-09-26 fix(pi-mission): emit real telemetry content plus drive-status metrics
    expected_metrics was built purely from sensor-manifest NAMES (gps/imu/
    bump), which never matched the only two keys readings ever held, so
    build_telemetry_record's floor-and-ceiling rule dropped every real
    reading and stored an all-"missing" record. position -- the design
    spec's primary live-summary metric -- was never emitted at all.
    Add MP1_EXPECTED_METRICS in runtime_config and union it with the
    manifest in startup(); populate position/position_uncertainty_m/
    heading_deg/error_radius_m/nav_mode/waypoint_index in the readings.
    Add a DriveStatus dataclass and Esp32Link.read_drive_status() (plus
    FakeEsp32Link support) s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
    [esp32_link.py, runtime.py, runtime_config.py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]
2026-09-26 fix(pi-mission): evaluate GPS-loss safety from tick 1 and surface mission_alert
    _check_gps_loss returned immediately while _last_gps_fix_monotonic was
    None, and _read_position's dummy-seed path deliberately left it None. A
    cold boot under tree cover with zero real fixes ever acquired therefore
    never evaluated GPS-loss safety at all, however long dead reckoning ran.
    The dummy seed now starts the same grace-period clock: "never had a fix"
    is at least as unsafe as "just lost one".
    mission_alert was also set but never logged, never reported, and never
    cleared -- latched for the life of the process even after the condition
    resolved. Both checks now log on the transition in (not at tick rate),
    cl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
    [runtime.py]
2026-09-26 fix(pi-mission): resume the newest interrupted sweep session, not an arbitrary one
    list_unsynced_sweep_sessions has no ORDER BY, so candidates[0] was
    SQLite insertion order rather than recency -- with a stale
    interrupted-and-unsynced session still on disk alongside a newer one, a
    crash could resume the wrong sweep. Sort newest-first in the runtime
    (recency is the caller's policy, not the table's) and warn naming the
    ids being skipped when more than one candidate exists.
    [runtime.py]
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
